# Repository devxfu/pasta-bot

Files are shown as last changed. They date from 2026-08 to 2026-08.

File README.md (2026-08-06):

# pasta-bot
A two-wheeled autonomous ground vehicle made for Science Olympiad's Robot Tour event, affectionately referred to as **pasta-bot** because of the spaghetti code holding it together.

<p align="center">
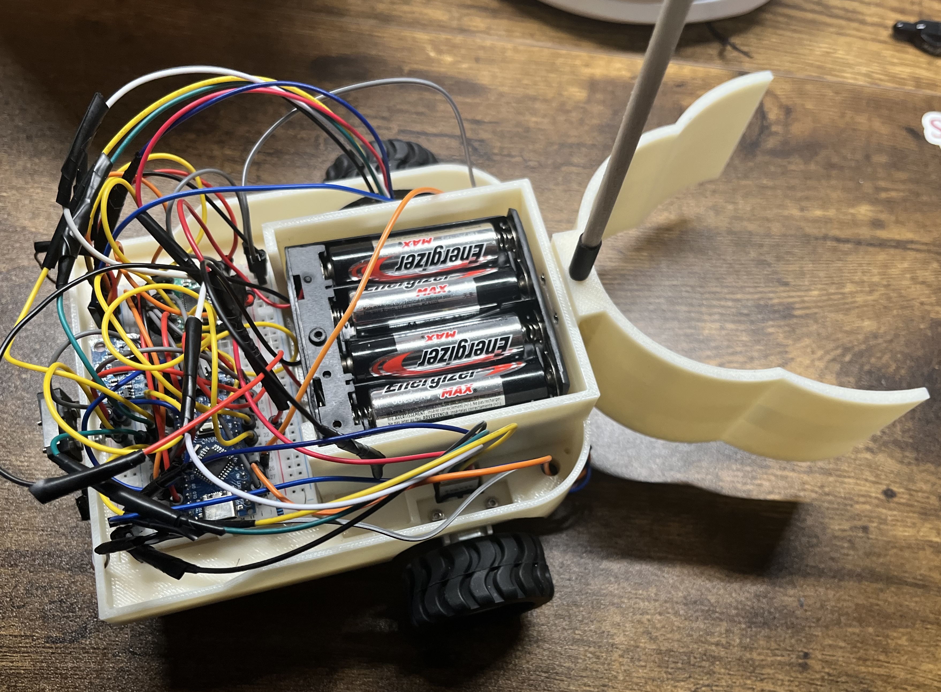
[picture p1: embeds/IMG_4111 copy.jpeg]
pasta-bot V2, finished
  
</p>

## About This Project
Created for educational purposes as a first attempt at a hardware project.

**no pre-built kits** were utilized in the making of this robot. Robot design, construction, material sourcing and programming were conducted independently. **OnShape** was used as CAD software of choice to design and 3D print custom parts for the robot. Specific materials utilized are listed in a section below.

Credit to Max Ignatenko for the [PID_V2 Arduino Library](https://docs.arduino.cc/libraries/pid_v2/), and the excellent blog at [TopFinishKits](https://topfinishkits.com/science-olympiad-blog/) that thoroughly explained PID concepts and steering mechanisms that inspired the creation of this vehicle. Finally, many thanks to our high school tech department for allowing the use of their 3D printers.

### A Brief overview of Robot Tour
The goal of the Robot Tour event is to guide a robot as close to a target point and target time as possible, all while avoiding obstacles.
  - Competitors are given the course setup (i.e. where the obstacles are, bonus gates, water bottle locations, start & end point) and target time only at the competition
    - Note: participants must plan the navigation paths **themselves** at the competition, pathfinding algorithms are strictly forbidden
  - Accessing special zones and pushing water bottles into these zones yield bonus
    - Note: only pushing is allowed, mechanisms such of those using **servos** are strictly banned
  - Harsh penalty for knocking over obstacle
  - Additional information can be seen on the [scoring sheet](https://www.soinc.org/sites/default/files/uploaded_files/RobotTourBC2026TeamChecklist_vB.pdf)

## Code Logic
**Due to** the fact that course information is not available until day of competition, we opted to hard code values for total dist of path chosen and target time, changing them only based on the information given at the time of competition. 

Given these constraints, the robot adjusts its own speed across the course to execute its route with perfect timing. Since motors have no conception of velocity, however, **PID** control loop using motor encoder data was used to control voltage supplied into motor driver pins, where physical constants (i.e. wheel diameter) translate encoder ticks into data interpretable in a physical context.

Basic kinematics was used in this timing-velocity calculation, as the robot necessitates time to accelerate into the ideal velocity, thereby affecting velocity calculations. The calculation therefore takes into account the trapezoidal acceleration profile implemented in the driving logic of the  vehicle and dynamically adjusts necessary speed across against its own timer every leg to account and adjust for errors.

Turning mechanism was solely dictated by IMU readings with a slight head room for angle errors. An attempt to use wheel-encoder data either as replacement or complement (through 1D Kalman sensor fusion technique) revealed that the wheel-encoder data is unfit for rotations in the robot, thereby poisoning the mostly accurate IMU readings robot (especially due to the small size of the bot).

A feed forward mechanism was implemented to supplement the PID control loop, derived from manual experiments in approximating the relationship between power supplied with wheel-encoder tick readings on floor. PID tunings were also adjusted using constants through empirical evidence.

Additional code implementations (such as addressing coasting after braking) can be found in the **src code in **this repo****

## Hardware Design
The robot was designed with the need to minimize its size in mind, because its rotational and translational movements can be controlled more precisely due to its size. As consequence, the design of chassis required careful planning. Below are a few decisions and their justifications:
- Since the battery compartment is the heaviest, trials in OnShape was conducted before 3D printing to assess center of mass locations. The current positioning of nearing the front of the robot was found to be optimal for placing center of mass only slightly behind wheel axis, which was believed to be optimal.
    - Additionally, quarters can be simply taped to the bottom-back portion of the robot to manually tune center of mass back towards the ball cast if the above belief is erroneous
- Many cutouts were made for wiring access on the robot platform in order to avoid tangling and potential loosening issues
- QTR-1A sensor implemented in the second iteration of the robot was placed directly under the claw as it has an optimal sensing range of only 3mm, so it was placed extremely close to the ground while remaining parallel about the dowel so it could stop the bot as soon as it detects drastic color change (i.e. finish line tape)
  
### Circuit Wiring Diagram
Generated from [app.cirkitdesigner.com](https://app.cirkitdesigner.com)

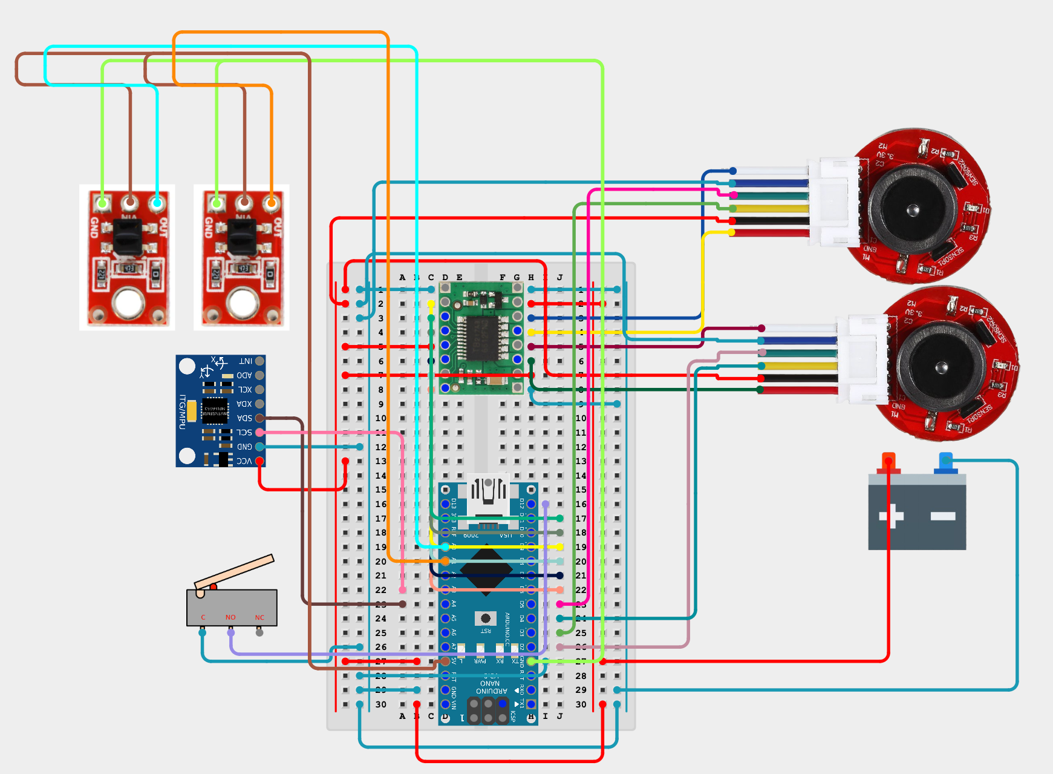
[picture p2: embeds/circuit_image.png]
cirkit wiring diagram

### Materials (total cost: ~$80)
The Robot is constructed of 3D printed parts and generic parts easily purchasable in a hardware store or on Amazon. Below is a list of parts, linked to the specific versions purchased:
- Generic Male to Female Jumper Wires
- Generic Resistors
- Generic Capacitors
- Screws, washers and nuts of varying sizes (typically M2 screws)
- [2 4xAA battery holders](https://www.robotshop.com/products/4xaa-square-battery-holder-cover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)
- [2x Wheels (opted for 42x19mm in dim)](https://www.robotshop.com/products/pololu-1090-wheel?variant=42360958484641)
- [Ball Caster with 3/8” Metal Ball](https://www.robotshop.com/products/pololu-ball-caster-3-8-in-metal-ball?variant=42359847649441)
- [Micro Limit Switch (Straight Lever)](https://www.robotshop.com/products/servocity-micro-limit-switch-straight-lever-2-pack?variant=44598088925345)
- [Generic MPU-5060 accelerometer/gyroscope for Arduino](https://www.amazon.com/HiLetgo-MPU-6050-Accelerometer-Gyroscope-Converter/dp/B00LP25V1A?th=1)
- [TB6612FNG DC Motor Driver](https://www.robotshop.com/products/pololu-dual-dc-motor-driver-1a-4-5v-3-5v-tb6612fng?variant=42358386524321)
- [Arduino Nano w/ USB-C Port (opted for a clone)](https://www.amazon.com/LAFVIN-Board-ATmega328P-Micro-Controller-Arduino/dp/B07G99NNXL/ref=sr_1_4?s=industrial)
- [Generic N20 Motors 12V 200 RPM with encoders attached](https://www.amazon.com/MECCANIXITY-Encoder-Gearbox-Electric-Reduction/dp/B0F8NGMRCX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)
- [N20 Motor Mount Bracket (easily 3D Printable)](https://www.amazon.com/MECCANIXITY-Mounting-Bracket-11-5mm-Screws/dp/B09NN6FQ78/ref=sr_1_4?s=industrial)
- [2x Pololu QTR-1A IR Sensor (optional)](https://www.robotshop.com/products/pololu-qtr-1a-reflectance-sensor-2pk?)
- [Robot Chassis (STL provided in this repo)](./CAD%20files/Chasis.stl)
- [Spacers for Ball cast/QTR sensors (STL provided in this repo)](./CAD%20files/spacers/)
- [Claw (STL provided in this repo)](./CAD%20files/Claw.stl)
- [Alignment tool for lining up the robot straight (STL provided in this repo)](./CAD%20files/alignment_tool.stl)
## Thoughts
While this vehicle was not perfect by all means, this project allowed me to learn about invaluable skills not yet covered through school, namely **CAD**, **elements of circuit design**, **exposure to engineering concepts**. As consequence, I am excited to keep learning, building and challenging myself with future projects :).

## Media
**V1 Chassis Print**

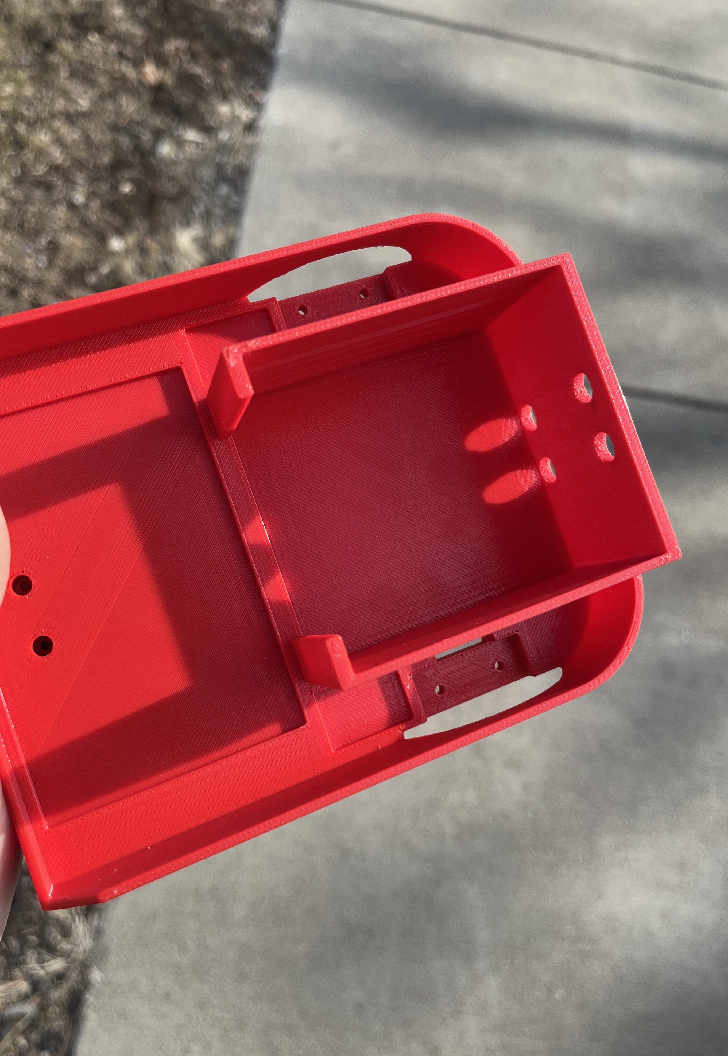
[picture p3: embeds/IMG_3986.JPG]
First Chassis Print


**V1 Claw Print**

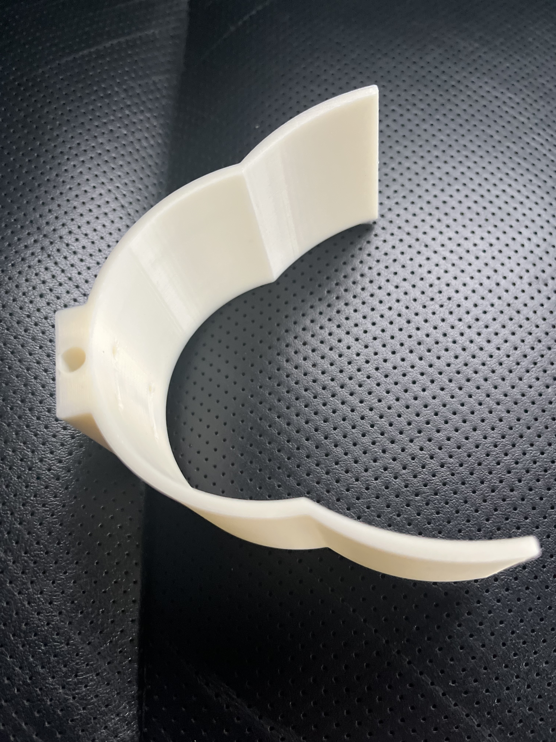
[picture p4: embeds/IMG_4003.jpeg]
First Claw Print


**Construction of V1 Robot**

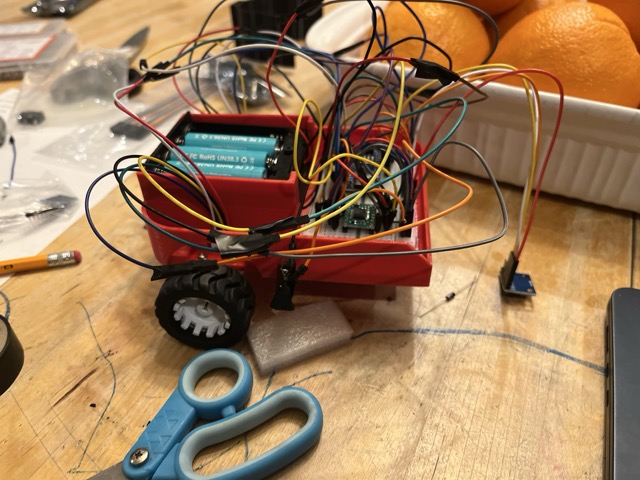
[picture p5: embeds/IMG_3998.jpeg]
Const Robot


**Demo of V1 Bot**

DemoTurns&Drive

**V2 (with IR sensor) Prints**

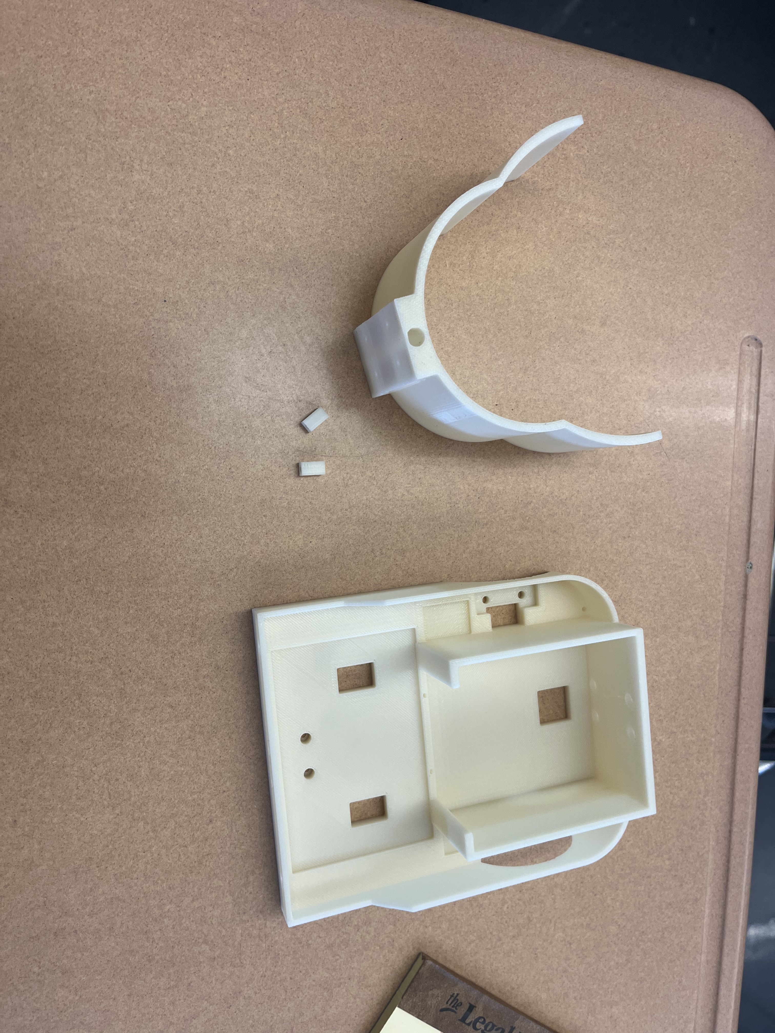
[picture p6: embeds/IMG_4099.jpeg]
V2 Prints


**Improved Claw Attachment Mechanism w/ IR attachment**

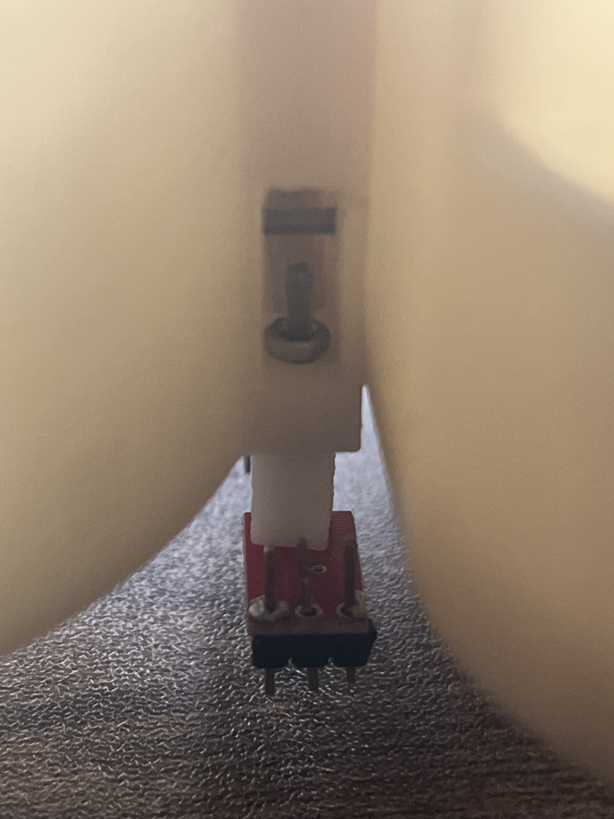
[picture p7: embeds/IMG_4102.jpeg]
Claw View


**Finished Re-construction of Robot w/ Changes**

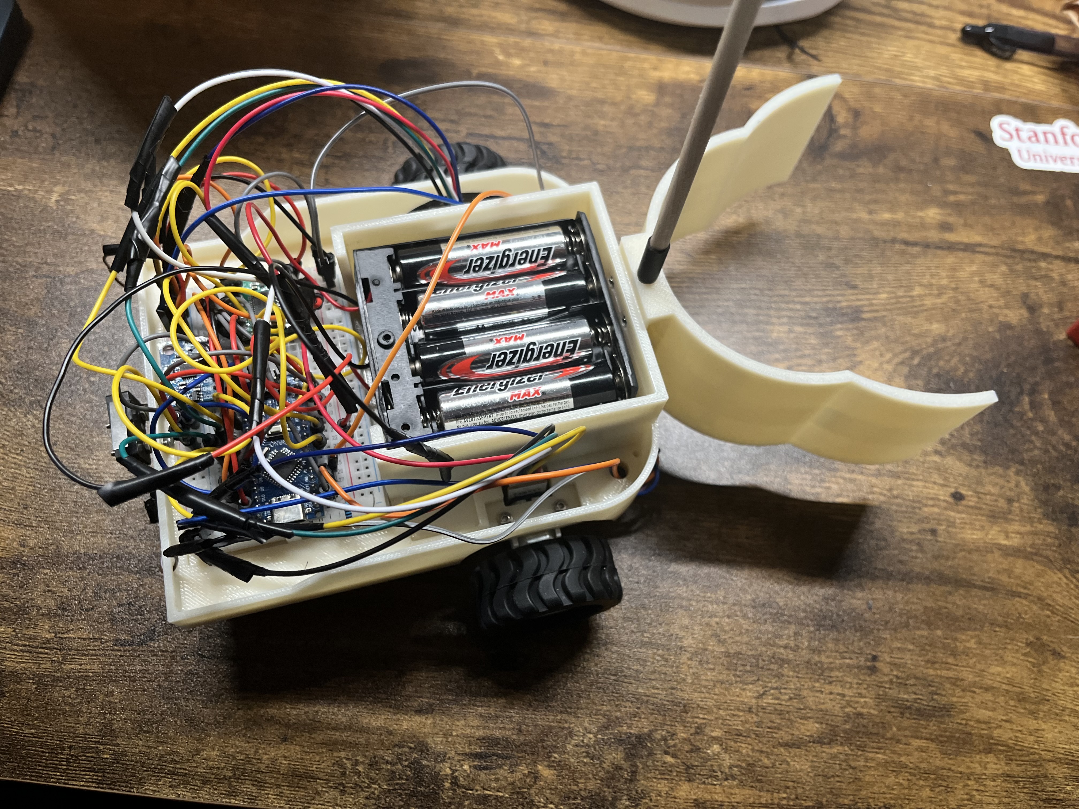
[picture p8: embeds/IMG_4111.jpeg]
V2Bot


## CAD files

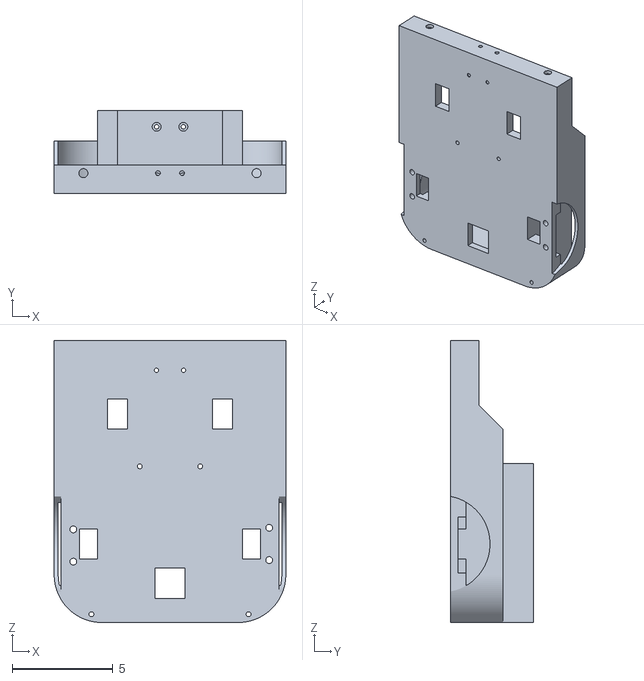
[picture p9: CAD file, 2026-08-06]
CAD files/Chasis.stl
11.5 x 4.10 x 14.0

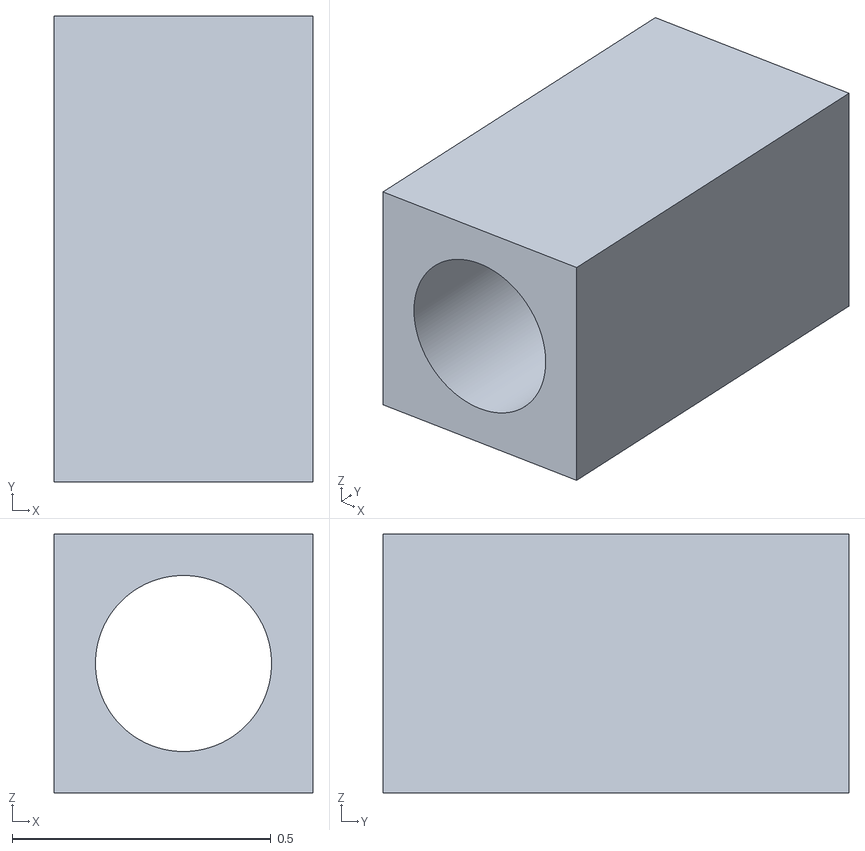
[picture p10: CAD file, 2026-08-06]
CAD files/spacers/QTR_Spacers.stl
0.5 x 0.9 x 0.5

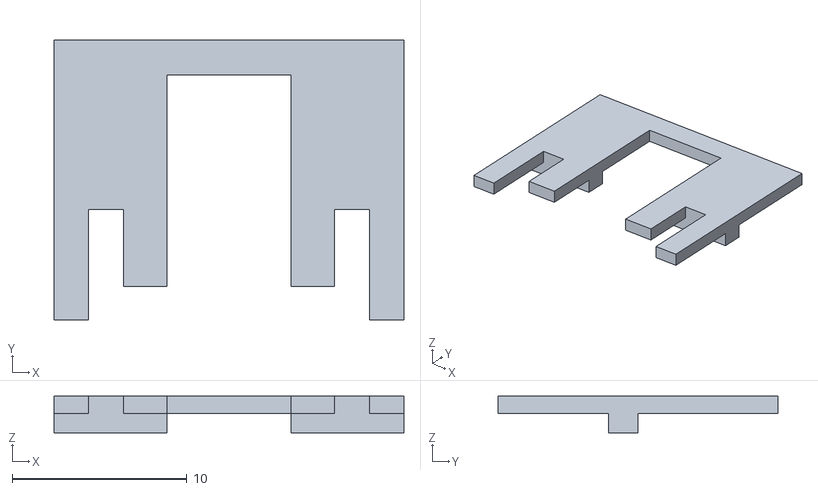
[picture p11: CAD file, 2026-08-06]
CAD files/alignment_tool.stl
20.0 x 16.0 x 2.10

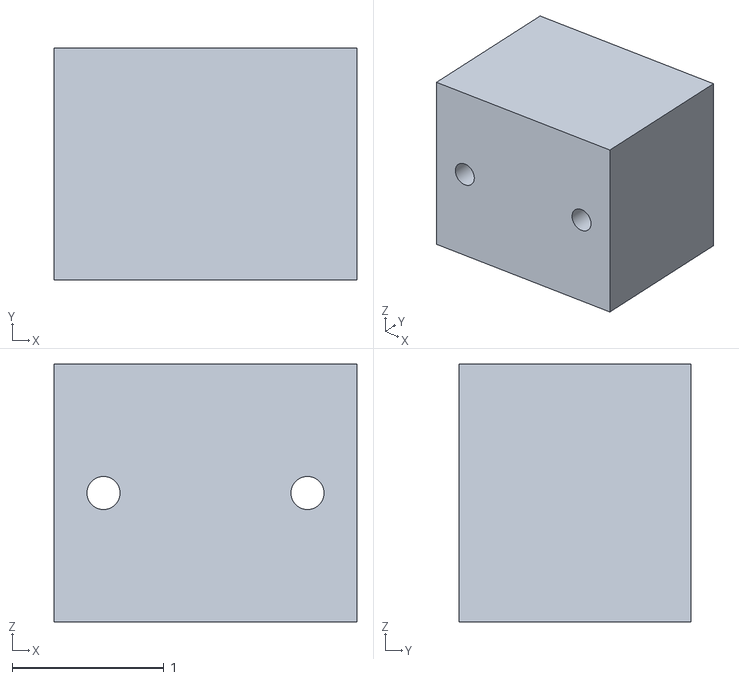
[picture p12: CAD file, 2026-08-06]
CAD files/spacers/ballcast_spacer.stl
2.00 x 1.53 x 1.70

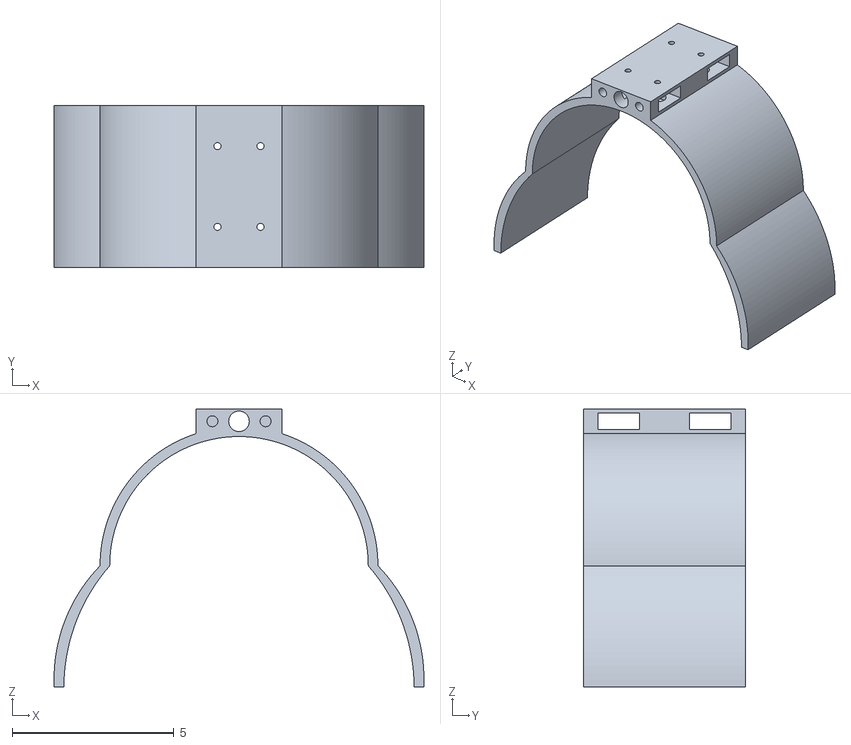
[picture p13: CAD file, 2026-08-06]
CAD files/Claw.stl
11.4 x 5.00 x 8.60

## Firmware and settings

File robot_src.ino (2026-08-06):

#include <Wire.h>
#include <avr/wdt.h>
#include <PID_v2.h>


const float TARGET_TIME_S = 61.0f;    // announced target time in seconds
const float TOTAL_COURSE_CM = 630.0f; // sum of ALL forward()/backward() distances in loop() below
const int TOTAL_TURNS = 9;            // total number of turns in your route


// PIN CONST
const int STBY = 13, START_SW = 12;
const int PWMA = 6, AIN1 = 7, AIN2 = 8, ENCA_L = 2, ENCB_L = 4;
const int PWMB = 9, BIN1 = 10, BIN2 = 11, ENCA_R = 3, ENCB_R = 5;
const int QTR_L = A0, QTR_R = A1;

// HARDWARE CONST
float WHEELBASE_CM = 13.75;
const float CM_PER_TICK = 0.018850f;

// QTR-SPECIFIC CONST
int qtr_baseline_L = 0;
int qtr_baseline_R = 0;
const int QTR_THRESHOLD = 200;
const float FINISH_CHECK_CM = 25.0f;
bool isFinalLeg = false;

// IMU-SPECIFIC CONST
float ideal_heading = 0.0;
volatile long left_counts = 0, right_counts = 0;
long prev_left_counts = 0, prev_right_counts = 0;
float gyro_z_offset = 0.0;
double current_heading = 0.0;
float raw_odometry_heading = 0.0;
float distance_traveled = 0.0;

// FEED-FORWARD & PID TUNING CONST
double Kff_L = 2.3699;
double Kff_R = 2.5371;

double Kp_vel = 1.2, Ki_vel = 0.4, Kd_vel = 0.0;
double Kp_head = 0.7, Ki_head = 0.05, Kd_head = 0.0;

// PID VAR
double target_heading = 0.0;
double steering_correction = 0.0;
double base_forward_speed = 0.0;
double target_speed_L = 0.0, target_speed_R = 0.0;
double actual_speed_L = 0.0, actual_speed_R = 0.0;
double output_PWM_L = 0.0, output_PWM_R = 0.0;

// PID CONTROLLER OBJECTS
PID headingPID(&current_heading, &steering_correction, &target_heading,
               Kp_head, Ki_head, Kd_head, DIRECT);
PID leftVelPID(&actual_speed_L, &output_PWM_L, &target_speed_L,
               Kp_vel, Ki_vel, Kd_vel, DIRECT);
PID rightVelPID(&actual_speed_R, &output_PWM_R, &target_speed_R,
                Kp_vel, Ki_vel, Kd_vel, DIRECT);

// MOTION CONST
const float MIN_SPEED_CMPS = 4.0;
const float TURN_SPEED = 14.0;
const float TURN_MIN_SPEED = 6.0;
const float TURN_THRESHOLD_DEG = 0.55;
const unsigned long TURN_SETTLE_MS = 100;
const unsigned long MOTION_TIMEOUT_MS = 25000;

float filt_speed_L = 0.0, filt_speed_R = 0.0;
const float SPEED_ALPHA = 0.35f;

// TIMING VAR
unsigned long run_start_ms = 0;
bool run_started = false;
float course_dist_covered = 0.0f;
int turns_completed = 0;
float time_per_turn_estimate = 3.68f; 

// MVMT DECLARATIONS
void forward(float target_distance, float max_speed = 50.0, bool reverse = false);
void baseDrive(float target_distance, float max_speed, bool reverse = false);
void backward(float dist, float speed = 40.0);
void left();
void right();
void turnToHeading(float delta_degrees);

// ENCODER INTERPRETER
void read_encoder_L() {
  left_counts += (digitalRead(ENCA_L) == digitalRead(ENCB_L)) ? -1 : 1;
}
void read_encoder_R() {
  right_counts += (digitalRead(ENCA_R) == digitalRead(ENCB_R)) ? 1 : -1;
}

// IMU CALIBRATION ON STARTUP
void setup() {

  MCUSR = 0;
  wdt_disable();

  Serial.begin(9600);

  pinMode(STBY, OUTPUT);
  digitalWrite(STBY, LOW);
  pinMode(PWMA, OUTPUT);
  pinMode(AIN1, OUTPUT);
  pinMode(AIN2, OUTPUT);
  pinMode(PWMB, OUTPUT);
  pinMode(BIN1, OUTPUT);
  pinMode(BIN2, OUTPUT);
  pinMode(START_SW, INPUT_PULLUP);
  pinMode(ENCA_L, INPUT);
  pinMode(ENCB_L, INPUT);
  pinMode(ENCA_R, INPUT);
  pinMode(ENCB_R, INPUT);

  attachInterrupt(digitalPinToInterrupt(ENCA_L), read_encoder_L, CHANGE);
  attachInterrupt(digitalPinToInterrupt(ENCA_R), read_encoder_R, CHANGE);

  delay(500);

  Wire.begin();
  Wire.setClock(100000);
  Wire.setWireTimeout(3000, true);  

  Wire.beginTransmission(0x68);
  Wire.write(0x6B);
  Wire.write(0);
  Wire.endTransmission(true);
  Wire.beginTransmission(0x68);
  Wire.write(0x1B);
  Wire.write(0x00);
  Wire.endTransmission(true);
  delay(250);

  calibrateIMU();
  wdt_enable(WDTO_1S);
  wdt_reset();
  calibrateQTR();

  headingPID.SetMode(AUTOMATIC);
  headingPID.SetOutputLimits(-12.0, 12.0);
  headingPID.SetSampleTime(20);

  leftVelPID.SetMode(AUTOMATIC);
  leftVelPID.SetOutputLimits(-75.0, 75.0);
  leftVelPID.SetSampleTime(20);

  rightVelPID.SetMode(AUTOMATIC);
  rightVelPID.SetOutputLimits(-75.0, 75.0);
  rightVelPID.SetSampleTime(20);

  Serial.println("Ready!");
}

// RESET ALL TEMP NAVIGATION-BASED VAR ON LEG END
void resetNavigation() {
  wdt_reset();
  delay(300);
  noInterrupts();
  left_counts = right_counts = prev_left_counts = prev_right_counts = 0;
  interrupts();
  distance_traveled = 0.0;
  raw_odometry_heading = 0.0;
  current_heading = 0.0;
  target_heading = 0.0;
  ideal_heading = 0.0;
  steering_correction = 0.0;
  filt_speed_L = 0.0;
  filt_speed_R = 0.0;
  isFinalLeg = false;

  course_dist_covered = 0.0f;
  turns_completed = 0;
  time_per_turn_estimate = 3.68f;

  flushAllPIDs();
  run_started = false;
  Serial.println("Navigation reset.");
}

// FLUSH PID; PREVENT ERROR WINDUP
void flushAllPIDs() {
  leftVelPID.SetMode(MANUAL);
  rightVelPID.SetMode(MANUAL);
  headingPID.SetMode(MANUAL);

  output_PWM_L = 0.0;
  output_PWM_R = 0.0;
  steering_correction = 0.0;

  leftVelPID.SetMode(AUTOMATIC);
  rightVelPID.SetMode(AUTOMATIC);
  headingPID.SetMode(AUTOMATIC);
}

// MAIN CODE TO EDIT AT COMPETITION: ctrl f (for easy access)
void loop() {
  wdt_reset();
  if (digitalRead(START_SW) == LOW) {
    resetNavigation();
    delay(500);
    forward(30);
    right();
    forward(100);
    left();
    forward(50);
    right();
    forward(50);
    left();
    forward(50);
    backward(50);
    left();
    forward(50);
    right();
    forward(50);
    left();
    forward(50);
    right();
    forward(50);
    right();
    forward(50);
    isFinalLeg = true;
    backward(50);
    isFinalLeg = false;

    while (digitalRead(START_SW) == LOW) {
      wdt_reset();
      delay(10);
    }
    wdt_reset();
    delay(500);
  }
}

// forward logic; dynamic speed based on turns and time remaining 
void forward(float target_distance, float max_speed, bool reverse) {
  if (!run_started) {
    run_start_ms = millis();
    run_started = true;
  }

  float elapsed_s = (millis() - run_start_ms) / 1000.0f;
  int turns_remaining = TOTAL_TURNS - turns_completed;
  float future_turn_budget_s = turns_remaining * time_per_turn_estimate;
  float remaining_time_s = TARGET_TIME_S - elapsed_s - future_turn_budget_s;
  float remaining_dist_cm = TOTAL_COURSE_CM - course_dist_covered;

  float segment_max_speed = max_speed;
  if (remaining_time_s > 0.5f && remaining_dist_cm > 1.0f) {
    float required_speed = remaining_dist_cm / remaining_time_s;
    segment_max_speed = constrain(required_speed, (float)MIN_SPEED_CMPS, max_speed);

    Serial.print("Seg max speed: ");
    Serial.print(segment_max_speed);
    Serial.print(" | Remaining time: ");
    Serial.print(remaining_time_s);
    Serial.print(" | Remaining dist: ");
    Serial.println(remaining_dist_cm);
  }

  baseDrive(target_distance, segment_max_speed, reverse);
  course_dist_covered += target_distance;
}

// use forward logic for moving backwards
void backward(float dist, float speed) {
  forward(dist, speed, true);
}

// movement logic
void baseDrive(float target_distance, float max_speed, bool reverse) {
  digitalWrite(STBY, HIGH);
  delay(50);
  noInterrupts();
  left_counts = right_counts = prev_left_counts = prev_right_counts = 0;
  interrupts();

  distance_traveled = 0.0;
  filt_speed_L = 0.0;
  filt_speed_R = 0.0;
  target_heading = ideal_heading;
  steering_correction = 0.0;

  float dir = reverse ? -1.0f : 1.0f;
  current_heading = current_heading;  // empirical evidence shows current_heading leads to better results; could maybe experiment with using ideal_heading

  flushAllPIDs();

  unsigned long prev_micros = micros();
  unsigned long start_millis = millis();

  const float ACCEL = 40.0f;
  float dynamic_decel = 40.0f;
  bool reached_max_speed = false;
  float current_target_speed = MIN_SPEED_CMPS;
  long snap_L = 0, snap_R = 0;
  int stall_ticks_L = 0, stall_ticks_R = 0;
  float boost_L = 0.0f, boost_R = 0.0f;
  const int STALL_CONFIRM_TICKS = 2;
  const float BOOST_RATE = 15.0f;
  const float BOOST_MAX = 60.0f;
  const float BOOST_DECAY = 20.0f;
  noInterrupts();
  snap_L = left_counts;
  snap_R = right_counts;
  interrupts();
  while (true) {
    // Attempt to create a trapezoidal acceleration profile
    unsigned long now_micros = micros();

    if (now_micros - prev_micros >= 20000UL) {
      wdt_reset();
      float dt = (now_micros - prev_micros) / 1000000.0f;
      prev_micros = now_micros;

      updateStateEstimator(dt, false);
      float remaining = target_distance - distance_traveled;
      if (checkFinishLine(remaining)) {
        activeBrake();
        return;
      }
      if (millis() - start_millis > MOTION_TIMEOUT_MS) {
        emergencyStop();
        return;
      }

      if (!reached_max_speed && current_target_speed >= max_speed) {
        reached_max_speed = true;
        float vf_sq = max_speed * max_speed;
        float vi_sq = MIN_SPEED_CMPS * MIN_SPEED_CMPS;
        if (distance_traveled > 0.5f && vf_sq > vi_sq) {
          dynamic_decel = (vf_sq - vi_sq) / (2.0f * distance_traveled);
          dynamic_decel = constrain(dynamic_decel, 10.0f, 80.0f);
        }
      }

      float avg_speed = (abs(actual_speed_L) + abs(actual_speed_R)) / 2.0f;
      // for if robot physically coast after brake
      float stop_trigger = max(0.1f, avg_speed * 0.03f);
      if (remaining <= stop_trigger) {
        Serial.print("Move finished, dist: ");
        Serial.println(distance_traveled);
        activeBrake();
        return;
      }

      float safe_braking_speed = sqrt(2.0f * dynamic_decel * remaining);
      float desired_speed = min(max_speed, safe_braking_speed);
      desired_speed = max((float)MIN_SPEED_CMPS, desired_speed);

      if (current_target_speed < desired_speed) {
        current_target_speed += ACCEL * dt;
        current_target_speed = min(current_target_speed, desired_speed);
      } else {
        current_target_speed -= dynamic_decel * dt;
        current_target_speed = max(current_target_speed, desired_speed);
      }

      base_forward_speed = current_target_speed;

      headingPID.Compute();

      target_speed_L = (dir * base_forward_speed) - steering_correction;
      target_speed_R = (dir * base_forward_speed) + steering_correction;

      noInterrupts();
      long cur_L = left_counts;
      long cur_R = right_counts;
      interrupts();
      // prevent stall from too little speed; relies on encoder reading to judge whether robot is moving with traction on ground
      bool wantMove = (current_target_speed > 1.0f);

      if (wantMove && abs(cur_L - snap_L) < 5) {
        stall_ticks_L++;
        if (stall_ticks_L >= STALL_CONFIRM_TICKS) boost_L = min(boost_L + BOOST_RATE, BOOST_MAX);
      } else {
        stall_ticks_L = 0;
        boost_L = max(boost_L - BOOST_DECAY, 0.0f);
      }
      snap_L = cur_L;

      if (wantMove && abs(cur_R - snap_R) < 5) {
        stall_ticks_R++;
        if (stall_ticks_R >= STALL_CONFIRM_TICKS) boost_R = min(boost_R + BOOST_RATE, BOOST_MAX);
      } else {
        stall_ticks_R = 0;
        boost_R = max(boost_R - BOOST_DECAY, 0.0f);
      }
      snap_R = cur_R;

      double dir_L = (target_speed_L >= 0) ? 1.0 : -1.0;
      double dir_R = (target_speed_R >= 0) ? 1.0 : -1.0;
      leftVelPID.Compute();
      rightVelPID.Compute();
      double final_pwm_L = constrain(output_PWM_L + Kff_L * target_speed_L + dir_L * boost_L, -255.0, 255.0);
      double final_pwm_R = constrain(output_PWM_R + Kff_R * target_speed_R + dir_R * boost_R, -255.0, 255.0);
      driveMotor(1, final_pwm_L);
      driveMotor(2, final_pwm_R);
    }
  }
}

// turning logics; repositions robot to desired dowel position through translations
void left() {
  unsigned long t_start = millis();
  baseDrive(5.2, 10.0, false);
  turnToHeading(90.0);
  baseDrive(3.75, 10.0, true);
  float actual_turn_s = (millis() - t_start) / 1000.0f;
  time_per_turn_estimate = (0.7f * time_per_turn_estimate) + (0.3f * actual_turn_s);
  turns_completed++;
}

void right() {
  unsigned long t_start = millis();
  baseDrive(3.75, 10.0, false);
  turnToHeading(-90.0);
  baseDrive(5.20, 10.0, true);
  float actual_turn_s = (millis() - t_start) / 1000.0f;
  time_per_turn_estimate = (0.7f * time_per_turn_estimate) + (0.3f * actual_turn_s);
  turns_completed++;
}
// entirely IMU-based turn system; encoder was tested but unfortunately too inaccurate esp with water bottle
void turnToHeading(float delta_degrees) {
  unsigned long turn_start_ms = millis();
  digitalWrite(STBY, HIGH);
  noInterrupts();
  left_counts = right_counts = prev_left_counts = prev_right_counts = 0;
  interrupts();
  distance_traveled = 0.0;
  flushAllPIDs();

  ideal_heading += delta_degrees;
  float goal_heading = ideal_heading;

  const float T_ACCEL = 30.0f;
  float T_DECEL = 30.0f;            
  float current_min_speed = TURN_MIN_SPEED;
  float current_turn_speed = TURN_MIN_SPEED;
  bool detected_heavy = false;

  unsigned long settled_since = 0;
  bool settling = false;
  unsigned long prev_micros = micros();

  long snap_L = 0, snap_R = 0;
  int stall_ticks_L = 0, stall_ticks_R = 0;
  float boost_L = 0.0f, boost_R = 0.0f;
  const int STALL_CONFIRM_TICKS = 2;
  const float BOOST_RATE = 15.0f;
  const float BOOST_MAX = 60.0f;
  const float BOOST_DECAY = 20.0f;
  noInterrupts();
  snap_L = left_counts;
  snap_R = right_counts;
  interrupts();

  while (true) {
    unsigned long now_micros = micros();
    if (now_micros - prev_micros >= 20000UL) {
      wdt_reset();
      float dt = (now_micros - prev_micros) / 1000000.0f;
      prev_micros = now_micros;
      updateStateEstimator(dt, true);

      if (millis() - turn_start_ms > MOTION_TIMEOUT_MS) {
        emergencyStop();
        return;
      }

      // higher floor speed & brakes earlier if heavier item detected (i.e. a water bottle from course)
      if (!detected_heavy && (boost_L > 20.0f || boost_R > 20.0f)) {
        detected_heavy = true;
        T_DECEL = 45.0f;
        current_min_speed = 10.0f;
        Serial.println("Heavy load detected - adjusting braking curve");
      }

      float error = goal_heading - current_heading;
      float abs_error = abs(error);

      if (abs_error <= TURN_THRESHOLD_DEG) {
        if (!settling) {
          settling = true;
          settled_since = millis();
          flushAllPIDs();
          boost_L = boost_R = 0.0f;
        }
        if (millis() - settled_since >= TURN_SETTLE_MS) {
          activeBrake();
          return;
        }
        current_turn_speed = 0.0f;
      } else {
        settling = false;
        float remaining_dist_cm = abs_error * (PI / 180.0f) * (WHEELBASE_CM / 2.0f);
        float safe_brake = sqrt(2.0f * T_DECEL * remaining_dist_cm);
        float desired_speed = max(current_min_speed, min((float)TURN_SPEED, safe_brake));
        if (current_turn_speed < desired_speed)
          current_turn_speed = min(current_turn_speed + T_ACCEL * dt, desired_speed);
        else
          current_turn_speed = max(current_turn_speed - T_DECEL * dt, desired_speed);
      }

      if (error > 0) {
        target_speed_L = -current_turn_speed;
        target_speed_R = current_turn_speed;
      } else {
        target_speed_L = current_turn_speed;
        target_speed_R = -current_turn_speed;
      }

      noInterrupts();
      long cur_L = left_counts;
      long cur_R = right_counts;
      interrupts();
      bool wantMove = (abs(target_speed_L) > 1.0f);

      if (wantMove && abs(cur_L - snap_L) < 5) {
        stall_ticks_L++;
        if (stall_ticks_L >= STALL_CONFIRM_TICKS) boost_L = min(boost_L + BOOST_RATE, BOOST_MAX);
      } else {
        stall_ticks_L = 0;
        boost_L = max(boost_L - BOOST_DECAY, 0.0f);
      }
      snap_L = cur_L;

      if (wantMove && abs(cur_R - snap_R) < 5) {
        stall_ticks_R++;
        if (stall_ticks_R >= STALL_CONFIRM_TICKS) boost_R = min(boost_R + BOOST_RATE, BOOST_MAX);
      } else {
        stall_ticks_R = 0;
        boost_R = max(boost_R - BOOST_DECAY, 0.0f);
      }
      snap_R = cur_R;

      double dir_L = (target_speed_L >= 0) ? 1.0 : -1.0;
      double dir_R = (target_speed_R >= 0) ? 1.0 : -1.0;
      leftVelPID.Compute();
      rightVelPID.Compute();
      double pwm_L = constrain(output_PWM_L + Kff_L * target_speed_L + dir_L * boost_L, -255.0, 255.0);
      double pwm_R = constrain(output_PWM_R + Kff_R * target_speed_R + dir_R * boost_R, -255.0, 255.0);
      driveMotor(1, pwm_L);
      driveMotor(2, pwm_R);
    }
  }
}

// estimates the state of robot at all times
void updateStateEstimator(float dt, bool is_turning) {
  noInterrupts();
  long cur_left = left_counts;
  long cur_right = right_counts;
  interrupts();

  long dL = cur_left - prev_left_counts;
  long dR = cur_right - prev_right_counts;
  prev_left_counts = cur_left;
  prev_right_counts = cur_right;

  float inst_speed_L = (dL * CM_PER_TICK) / dt;
  float inst_speed_R = (dR * CM_PER_TICK) / dt;

  filt_speed_L = (SPEED_ALPHA * inst_speed_L) + ((1.0f - SPEED_ALPHA) * filt_speed_L);
  filt_speed_R = (SPEED_ALPHA * inst_speed_R) + ((1.0f - SPEED_ALPHA) * filt_speed_R);

  actual_speed_L = filt_speed_L;
  actual_speed_R = filt_speed_R;

  float dist_L = dL * CM_PER_TICK;
  float dist_R = dR * CM_PER_TICK;
  distance_traveled += abs((dist_L + dist_R) / 2.0f);

  float delta_theta_odom_deg = ((dist_R - dist_L) / WHEELBASE_CM) * (180.0f / PI);
  raw_odometry_heading += delta_theta_odom_deg;

  float gyro_rate_dps = 0.0f;
  Wire.beginTransmission(0x68);
  Wire.write(0x47);
  if (Wire.endTransmission(false) == 0) {
    uint8_t bytes_received = Wire.requestFrom(0x68, 2, true);
    if (bytes_received >= 2) {
      int16_t gyro_z_raw = (Wire.read() << 8) | Wire.read();
      gyro_rate_dps = (gyro_z_raw - gyro_z_offset) / 129.3f;
      float gyro_deadzone = is_turning ? 0.15f : 0.5f;
      if (abs(gyro_rate_dps) < gyro_deadzone) gyro_rate_dps = 0.0f;
    }
  }
  current_heading += gyro_rate_dps * dt;
}

// hardware helpers
void activeBrake() {
  digitalWrite(AIN1, HIGH);
  digitalWrite(AIN2, HIGH);
  analogWrite(PWMA, 255);
  digitalWrite(BIN1, HIGH);
  digitalWrite(BIN2, HIGH);
  analogWrite(PWMB, 255);
  smartDelay(80, true);
  digitalWrite(STBY, LOW);
}

void emergencyStop() {
  digitalWrite(STBY, LOW);
}

void driveMotor(int motor, double pwm) {
  int pwm_val = (int)abs(pwm);
  pwm_val = constrain(pwm_val, 0, 255);
  bool fwd = (pwm >= 0);
  if (motor == 1) {
    digitalWrite(AIN1, fwd ? LOW : HIGH);
    digitalWrite(AIN2, fwd ? HIGH : LOW);
    analogWrite(PWMA, pwm_val);
  } else {
    digitalWrite(BIN1, fwd ? LOW : HIGH);
    digitalWrite(BIN2, fwd ? HIGH : LOW);
    analogWrite(PWMB, pwm_val);
  }
}

void calibrateIMU() {
  wdt_disable();
  while (true) {
    Serial.println("Calibrating IMU... DO NOT MOVE.");
    delay(1000);

    long gyro_sum = 0;
    int16_t min_val = 32767;
    int16_t max_val = -32768;
    int valid_reads = 0;

    for (int i = 0; i < 200; i++) {
      Wire.beginTransmission(0x68);
      Wire.write(0x47);
      if (Wire.endTransmission(false) != 0) {
        delay(5);
        continue;
      }
      if (Wire.requestFrom(0x68, 2, true) < 2) {
        delay(5);
        continue;
      }

      int16_t val = (Wire.read() << 8) | Wire.read();
      gyro_sum += val;
      if (val < min_val) min_val = val;
      if (val > max_val) max_val = val;
      valid_reads++;
      delay(5);
    }

    if (valid_reads < 150) {
      Serial.println("IMU read failure during calibration. Retrying...");
      continue;
    }

    int32_t spread = (int32_t)max_val - (int32_t)min_val;
    if (spread < 130) {
      gyro_z_offset = gyro_sum / (float)valid_reads;
      Serial.println("IMU calibrated. Ready. Flip switch to start.");
      return;
    } else {
      Serial.print("Movement detected! Spread: ");
      Serial.println(spread);
    }
  }
}

void smartDelay(unsigned long ms, bool is_turning) {
  unsigned long start_millis = millis();
  unsigned long prev_micros = micros();

  while (millis() - start_millis < ms) {
    wdt_reset();
    unsigned long now_micros = micros();
    if (now_micros - prev_micros >= 20000UL) {
      float dt = (now_micros - prev_micros) / 1000000.0f;
      prev_micros = now_micros;
      updateStateEstimator(dt, is_turning);
    }
  }
}
bool checkFinishLine(float remaining_cm) {
  if (!isFinalLeg) return false;
  if (remaining_cm > FINISH_CHECK_CM) return false;

  int valL = analogRead(QTR_L);
  int valR = analogRead(QTR_R);

  bool hitL = abs(valL - qtr_baseline_L) > QTR_THRESHOLD;
  bool hitR = abs(valR - qtr_baseline_R) > QTR_THRESHOLD;

  if (hitL || hitR) {
    Serial.print("FINISH LINE DETECTED! L=");
    Serial.print(valL);
    Serial.print(" R=");
    Serial.println(valR);
    return true;
  }
  return false;
}
void calibrateQTR() {
  long sumL = 0, sumR = 0;
  for (int i = 0; i < 100; i++) {
    sumL += analogRead(QTR_L);
    sumR += analogRead(QTR_R);
    delay(5);
  }
  qtr_baseline_L = sumL / 100;
  qtr_baseline_R = sumR / 100;
  Serial.print("QTR baseline L: ");
  Serial.println(qtr_baseline_L);
  Serial.print("QTR baseline R: ");
  Serial.println(qtr_baseline_R);
}

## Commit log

2026-08-06 Created documentation for bot in README, compiled images of robot, and uploaded robot src code + CAD STL files
    [Chasis.stl, Claw.stl, QTR_Spacers.stl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]
2026-08-06 added circuit diagram, shifted sections
2026-08-06 added relative linking to stl files in README
    [QTR_Spacers.stl, ballcast_spacer.stl]
